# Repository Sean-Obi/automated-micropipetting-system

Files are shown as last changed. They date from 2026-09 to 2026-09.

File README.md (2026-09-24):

# Automated Micropipetting System - Gantry + Linear Actuator + Touchscreen

A low-cost, bench-top pipetting robot that lets users with tremors, fatigue or limited upper-limb mobility pipette independently. A modified Ender-3 gantry positions an actuator-driven 3D-printed micropipette over labware, and the whole run is set up from a Nextion touchscreen: pick a source, the destination wells and a volume, then press start.

Built as the Design & Prototyping group project built by nine second-year Molecular Bioengineering students at Imperial College London, supervised by Dr Ian Radcliffe.

> ❗️**Prototype, not a certified lab instrument.** Accuracy was validated on the bench only. Don't use it for regulated or clinical work.

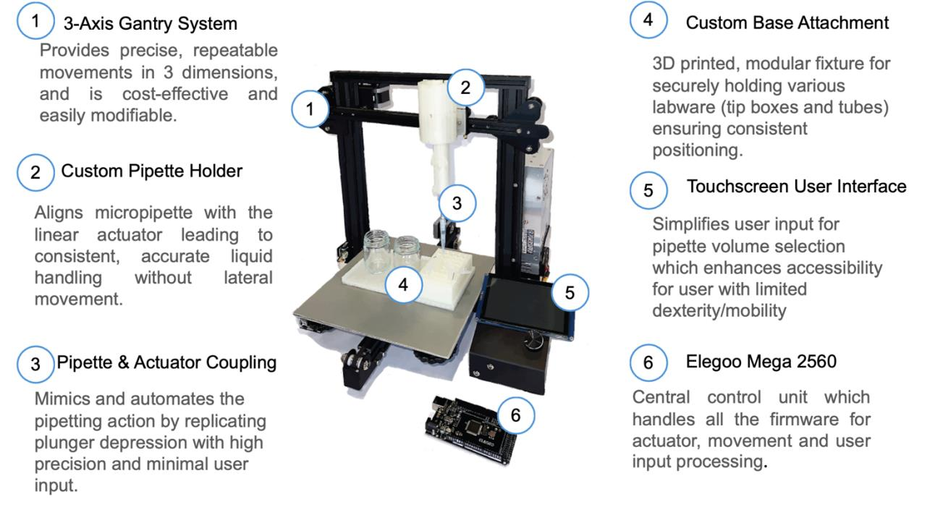
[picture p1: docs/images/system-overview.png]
System overview


---

## Features
- **3-axis Cartesian gantry** built on a Creality Ender-3 frame, with A4988 drivers and end-stop homing on every axis.
- **Coordinated XY motion** using Bresenham-style interpolation, so both axes arrive together. Z always retracts to a safe height before any travel.
- **Actuator-driven pipette.** A 12 V linear actuator presses the plunger of an open-source, ISO 8655-compliant 3D-printed micropipette.
- **Touchscreen workflow.** Source → wells → volume → start on a 4.3" Nextion HMI, with input validation done on the display.
- **Tactile keypad** (4×3) as an alternative input, plus a **buzzer** for audio feedback at the start and end of each job.
- **Modular PLA base** with a 5×8 tube rack and two beaker slots in fixed, grooved positions.
- **£483.53** material cost, against more than £35,000 for commercial liquid handlers.

---

## Hardware
- Elegoo Mega 2560 R3 (Arduino Mega compatible)
- Creality Ender-3 3D printer (frame, rails, NEMA17 steppers, end-stops, PSU)
- 3 × A4988 stepper driver modules
- Actuonix Linear Actuator Control (LAC) board + linear actuator
- 3D-printed adjustable micropipette (3 mL syringe) + custom pipette/actuator holder
- Nextion NX4827T043 4.3" HMI touchscreen + microSD card
- 4×3 membrane keypad, piezo buzzer
- 3 × LM2596 buck converters, custom interface PCB

Full part list with suppliers and prices: [`hardware/BOM.csv`](hardware/BOM.csv).

### Interface PCB
A 2-layer, 132 × 80 mm board that carries the three A4988 drivers, power inputs and all device connectors, with a 2×14 header to the Mega. KiCad files and Gerbers are in [`hardware/`](hardware/).

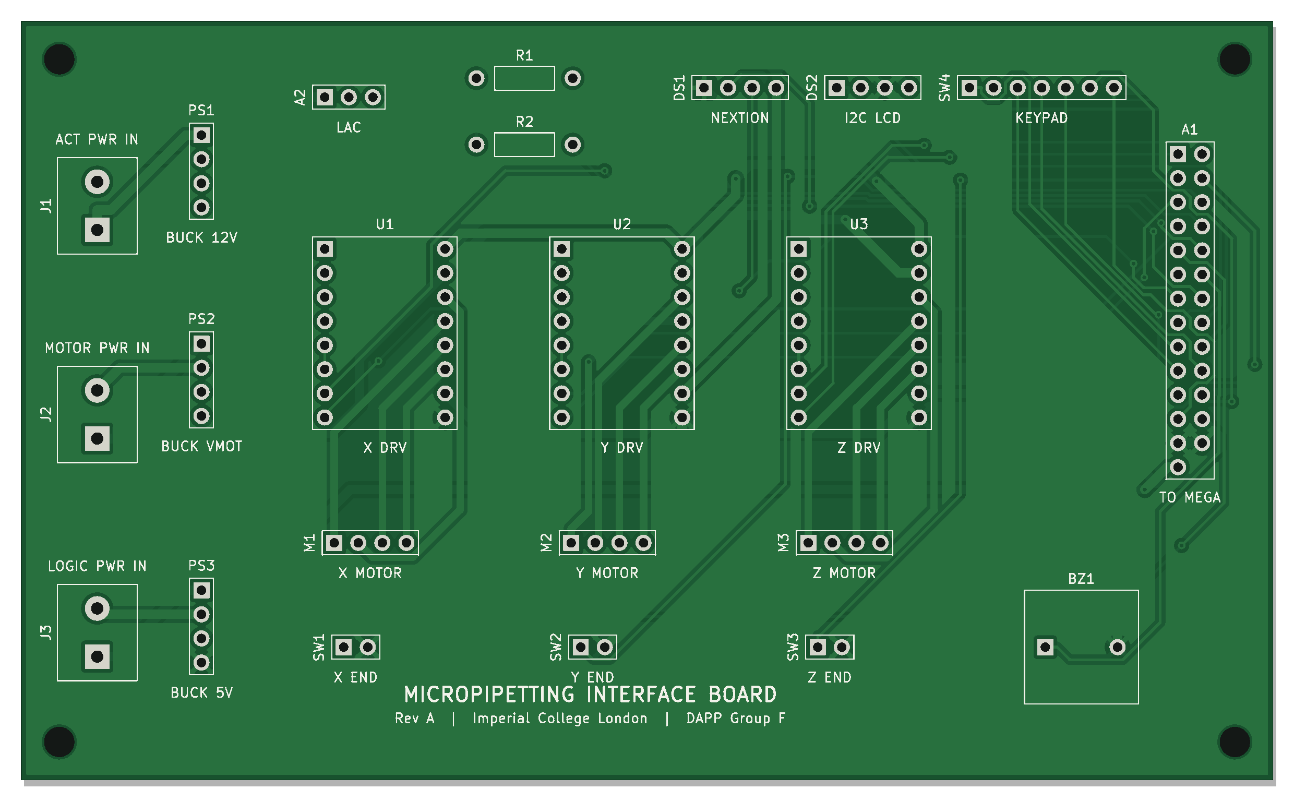
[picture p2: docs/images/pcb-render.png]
PCB render


> The layout in this repo is a 2026 reconstruction from the report schematic, not the original files sent to JLCPCB. See [`hardware/README.md`](hardware/README.md#board-layout).

### Power
- Mains supplies the Ender-3 PSU (24 W total draw).
- **12 V rail** (via buck converter) powers the LAC board and actuator.
- **5 V rail** (via buck converters) powers the Mega, the A4988 logic and the Nextion.
- A separate buck converter supplies the stepper motor voltage (VMOT).

> Set every LM2596 output with a multimeter **before** connecting anything. They ship at arbitrary voltages.

---

## Pinout / Wiring

| Component | Signal | Mega Pin |
|---|---|---|
| X axis | STEP / DIR / End-stop | **6** / **7** / **5** |
| Y axis | STEP / DIR / End-stop | **9** / **10** / **8** |
| Z axis | STEP / DIR / End-stop | **12** / **13** / **11** |
| LAC board | VC (position signal) | **4** (via R2, with R1 pull-up) |
| Nextion | RX / TX | **TX1 (18)** / **RX1 (19)** |
| Keypad | Rows / columns | **22, 24, 26, 28, 30, 32, 34** |
| Buzzer | + | **2** |
| A4988 | VDD / VMOT | 5V / motor buck output |
| A4988 | SLP ↔ RST | Tied together |
| End-stops | Switch → GND | `INPUT_PULLUP`, triggered = `HIGH` |

> Note: the report's schematic figure shows DIR/STEP swapped, the buzzer on D52 and the Nextion on TX0/RX0. The table above follows the firmware, which is what actually ran. Full schematic: [`hardware/pcb_design.kicad_sch`](hardware/pcb_design.kicad_sch).

---

## Software Requirements
Arduino IDE 1.8+ or Arduino IDE 2.x. **No external libraries** are needed. The sketch only uses the Arduino core (`Serial`, `Serial1`, `tone()`).

For the touchscreen:
- **Nextion Editor** to edit the `.HMI` and compile the `.tft`.

---

## Installation
1. **Clone the repository**
   ```bash
   git clone https://github.com/your-username/automated-micropipetting-system.git
   cd automated-micropipetting-system
   ```
2. Wire the system per the pin table above, and set the A4988 current limits and buck converter voltages.
3. Open `firmware/pipetting_controller/pipetting_controller.ino` in the Arduino IDE.
4. Select **Board → Arduino Mega or Mega 2560** and the correct port.
5. **Verify/Compile**, then **Upload**.
6. Copy the Nextion `.tft` to a FAT32 microSD card, insert it into the display and power it on to flash.
7. (Optional) Open **Tools → Serial Monitor** at **9600 baud** to watch the job logs.

---

## Configuration

Edit these constants near the top of the sketch. All positions are in **steps from home**:

```cpp
const long Z_SAFE_HEIGHT = 1700;   // travel height between positions
const long Z_WORK_HEIGHT = 300;    // tip-in-liquid height
unsigned long stepDelayXY = 1500;  // µs, XY step half-period (lower = faster)
unsigned long stepDelayZ  = 1200;  // µs, Z step half-period
const long MAX_HOMING_STEPS_Z = MAX_BACKWARD_Z + 100;  // Z homing timeout
```

Labware positions come from calibration and must be re-measured if the base changes:
```cpp
Coord wells[]   = { { 890, 500 }, { 940, 500 }, ... };  // 5×8 rack, 50-step pitch
Coord beakers[] = { { 400, 700 }, { 670, 700 } };       // left, right
```

Step resolution (from calibration):
- **X:** ~0.199 mm/step
- **Y:** ~0.205 mm/step
- **Z:** 0.04 mm/step

---

## How It Works

1. **Homing**  
   At power-up, each axis drives toward its end-stop (X → Y → Z) to set an absolute zero. Z then rises to `Z_SAFE_HEIGHT`.

2. **Job Entry**  
   The user steps through the Nextion screens (source type → beaker or input well → output wells → volume). The display checks the inputs, then sends a single packet over `Serial1`, terminated by `#`.

3. **Packet Parsing**  
   `parsePacket()` decodes the ASCII fields (`I=` input well, `O=` output wells) and the 4-byte little-endian fields (`V=` volume, `B=` beaker side, `T=` source type), then plays a confirmation beep.

4. **Execution**  
   The gantry travels to the source and then to each output well in turn. At every stop, `holdZatWorkHeight()` lowers the tip, dwells for 3 s, then retracts. Z always returns to safe height before any XY move.

5. **Return**  
   The head goes back to (0, 0), the end melody plays, and the buffer clears ready for the next job.

---

## Usage

1. Plug in the system and wait for homing to finish.
2. Fill the source beaker or tubes and place them in the marked slots. Fit a fresh tip.
3. On the touchscreen, choose **Beaker** or **Tubes**, then pick the source.
4. Tap the output wells and press **Confirm**.
5. Enter the volume in µL and tap **Start Pipetting**.
6. Two beeps confirm the job, and a melody plays when the head is back home.
7. Remove the tip by hand. There is no auto-eject yet.

Full walkthrough with screenshots: [`docs/user-guide.md`](docs/user-guide.md).

---

## Data Output

### Serial Monitor (9600)
```
Ready to receive Nextion packets...
Input Well: 0
Output Wells: 12,13,14,
Volume: 74
Beaker Side: 1
Source Type: 1
```

### Nextion Packet Format
```
T=<4B> B=<4B> I=<digits> O=<d>,<d>,...; V=<4B> #
```
| Field | Meaning |
|---|---|
| `T` | Source type: 1 = beaker, 2 = tubes |
| `B` | Beaker side: 1 = left, 2 = right |
| `I` | Input well index (0–39) |
| `O` | Output well indices, `;`-terminated |
| `V` | Volume in µL |

### Debug Commands (USB Serial)
| Command | Action |
|---|---|
| `X0` | Re-home X |
| `Y0` | Re-home Y |
| `Z0` | Re-home Z |

---

## Results

- **Volume accuracy:** the pipette alone was calibrated to within ±1% of target. The actuator adds extra uncertainty at system level, and accuracy drops at low volumes.
- **Cross-contamination:** no visible carryover in dye-then-clear runs with tip changes. This was checked by eye only.
- **Gantry:** the step-to-distance response is linear on all axes ([calibration](docs/calibration.md)).
- **User testing (n = 20):**
  - 90% rated lab fit 4–5/5.
  - 75% needed minimal or no instructions.
  - The top requests were a bigger screen, larger touch targets and tactile buttons.

Full evaluation: [`docs/testing.md`](docs/testing.md).

---

## Troubleshooting

- **An axis runs into the frame during homing**
  - Check the end-stop wiring and that it reads `HIGH` when pressed (`LIMIT_PRESSED = HIGH`).
  - XY homing has no step limit. Cut power or press reset if a switch fails.

- **The touchscreen does nothing when you press Start**
  - Nextion TX must go to Mega **RX1 (19)** and Nextion RX to **TX1 (18)**. The crossover matters.
  - Both sides need to be at **9600 baud**.
  - Check that the packet ends with `#`. Watch the Serial Monitor for the `Input Well:` lines.

- **The tip misses the wells**
  - Re-home with `X0` / `Y0` / `Z0`. Position isn't re-homed between jobs, so lost steps accumulate.
  - Re-measure `wells[]` / `beakers[]` if the base has moved.

- **A motor stutters, skips or runs hot**
  - Re-set the A4988 current limit on the trim pot.
  - Increase `stepDelayXY` / `stepDelayZ` to slow the motion.
  - Check that VMOT is present and the driver has airflow or a heatsink.

- **A motor runs backwards**
  - Swap one coil pair (1A/1B) on that driver.

- **The tip doesn't reach the liquid, or it crashes into the tube bottom**
  - Adjust `Z_WORK_HEIGHT`.

---

## Notes & Limitations
- **The volume isn't used by the firmware yet.** `V=` is parsed and logged, but this sketch doesn't generate the actuator PWM. Actuation happens outside this file.
- **16-bit `int` on AVR.** The 4-byte field decoding shifts by 16 and 24 bits, which overflows a 16-bit `int`. It works only because the upper bytes are zero. It should use `int32_t`.
- **Everything is blocking.** There's no cancel or emergency stop mid-job.
- **The keypad isn't implemented here.** It is wired, but this sketch doesn't read it.
- **Tips are ejected manually.** Servo-driven ejection and a tip bin are on the roadmap.
- **Materials.** PLA parts suit prototyping only. The pipette–carriage joint needs a stiffer mount.
- **The volume range is inconsistent across sources.** The spec says 100–1000 µL, the UI guide 10–100 µL, and testing covered 30–100 µL.

More detail: [`firmware/README.md`](firmware/README.md#known-issues).

---

## Project Structure

```
automated-micropipetting-system/
├── firmware/
│   ├── pipetting_controller/
│   │   └── pipetting_controller.ino   # Gantry, homing, Nextion packet parser
│   └── README.md                      # Pinout, protocol, known issues
├── hardware/
│   ├── pcb_design.kicad_pro           # KiCad project
│   ├── pcb_design.kicad_sch           # Schematic
│   ├── pcb_design.kicad_pcb           # Board layout (reconstructed)
│   ├── pcb_design_gerbers.zip         # Gerbers + drill files
│   ├── apms.pretty/                   # Project footprint library
│   ├── pcb_design.pdf                 # Plotted schematic
│   ├── schematic.png                  # Original figure from the report
│   ├── BOM.csv                        # Bill of materials (£483.53)
│   ├── tools/                         # Schematic + board generation scripts
│   └── README.md                      # Power rails, drivers, wiring
├── hmi/
│   └── README.md                      # Nextion screen flow
├── cad/
│   └── README.md                      # SolidWorks parts (base, holders)
├── docs/
│   ├── images/                        # Figures
│   ├── calibration.md                 # Gantry step calibration
│   ├── testing.md                     # Accuracy, contamination, user testing
│   ├── user-guide.md                  # Operating instructions
│   └── final-report.pdf               # Full project report
└── README.md
```

---

## Team
Ben Jones · Jenna du Preez · Kailin Wang · Leonardo Grimaldi · **Sean Obi** · Sheena Ling · Sumaiyah Zaman · Tayeb Tadlaoui · Yasmine Marenzi

### My Contributions (Sean Obi)
- **PCB design.** Designed the custom interface PCB (schematic and layout), manufactured by JLCPCB.
- **Electronics lead.** System wiring and power distribution (12 V actuator rail, 5 V logic), and integration of the drivers, LAC board, keypad, display and buzzer.
- **Firmware.** Co-developed the Arduino controller: homing, XY motion and Nextion packet handling.
- **Gantry.** Assembled the Ender-3 conversion.
- **User testing.** Coordinated the n = 20 study.
- **Final report.** Co-authored it.

---

## Acknowledgements
- Dr Ian Radcliffe (supervisor)
- Imperial Disability Advisory Services and Dr Katherine Dean
- Ms Iris Latham (disability consultant) and Dr Tweety Tang (user-testing sessions)
- Brennan, Bokhari & Eddington: *Open Design 3D-Printable Adjustable Micropipette that Meets the ISO Standard for Accuracy* (Micromachines, 2018)
- Creality Ender-3 · Pololu A4988 · Actuonix LAC · Nextion Editor

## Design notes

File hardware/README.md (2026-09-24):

# Hardware

| File | Contents |
|---|---|
| `pcb_design.kicad_pro` | KiCad project (KiCad 7 format; opens in 7, 8 and 9) |
| `pcb_design.kicad_sch` | Schematic |
| `pcb_design.kicad_pcb` | Board layout (reconstructed; see below) |
| `pcb_design_gerbers.zip` | Gerbers and drill files exported from the reconstructed layout |
| `apms.pretty/`, `fp-lib-table` | Project footprint library |
| `pcb_design.pdf` | Plotted schematic |
| `schematic.png` | Original schematic figure from the report (Appendix F) |
| `tools/` | Scripts that generate the schematic and board |
| `BOM.csv` | Bill of materials |

---

## Board Layout

PCB render

> **Reconstruction.** The original 2025 layout files and the Gerbers sent to JLCPCB aren't in this repo. This layout was rebuilt in 2026 from the report's schematic figure and auto-routed with Freerouting. It is electrically equivalent to the schematic, but it is not the board that was manufactured.

**Board**
- 132 × 80 mm, 2 layers, 1.6 mm thick, with four M3 mounting holes.
- GND pour on both layers.

**Track widths**
| Net class | Nets | Width |
|---|---|---|
| Power | GND, +5V, VMOT, actuator and logic supply | 1.0 mm |
| Motor | Stepper coils | 0.8 mm |
| Signal | Everything else | 0.3 mm |

The board passes KiCad DRC with **0 violations and 0 unconnected pads**.

**On-board**
- 3 × Pololu-format A4988 sockets (X/Y/Z)
- R1/R2 on the LAC control line
- Buzzer
- 3 × 5.08 mm screw terminals for the power inputs

**Connected by header**
- Motors (4-pin) and end-stops (2-pin)
- The three LM2596 modules (IN+, IN−, OUT+, OUT−)
- LAC board, Nextion, legacy I²C LCD (not fitted) and keypad
- A 2×14 **TO MEGA** header carrying every Mega signal

---

## Schematic

The `.kicad_sch` is redrawn from the report figure, with two changes:

1. **It shows all three axes.** The original figure shows one representative driver, motor and end-stop.
2. **Its pin assignments follow the firmware, which is what actually ran.** Where the report figure differs, the firmware wins:

| Signal | Report figure | Schematic / firmware |
|---|---|---|
| X DIR / STEP | D6 / D7 | D7 / D6 |
| Buzzer | D52 | D2 |
| Nextion | TX0 / RX0 | Serial1: TX1 (D18), RX1 (D19) |

Connectivity uses net labels, so every connection is explicit. Every symbol has a footprint from the project library, and **Tools → Update PCB from Schematic** matches the layout.

Before building from these files, check these points against the physical build:

- The values of R1 and R2 on the LAC control line are not given in the report.
- The keypad pin order onto D22–D34 is as drawn in the report.
- `VMOT_GND` and `LAC_V-` are left as separate returns, as drawn. Tie them to GND if the supplies share a ground.

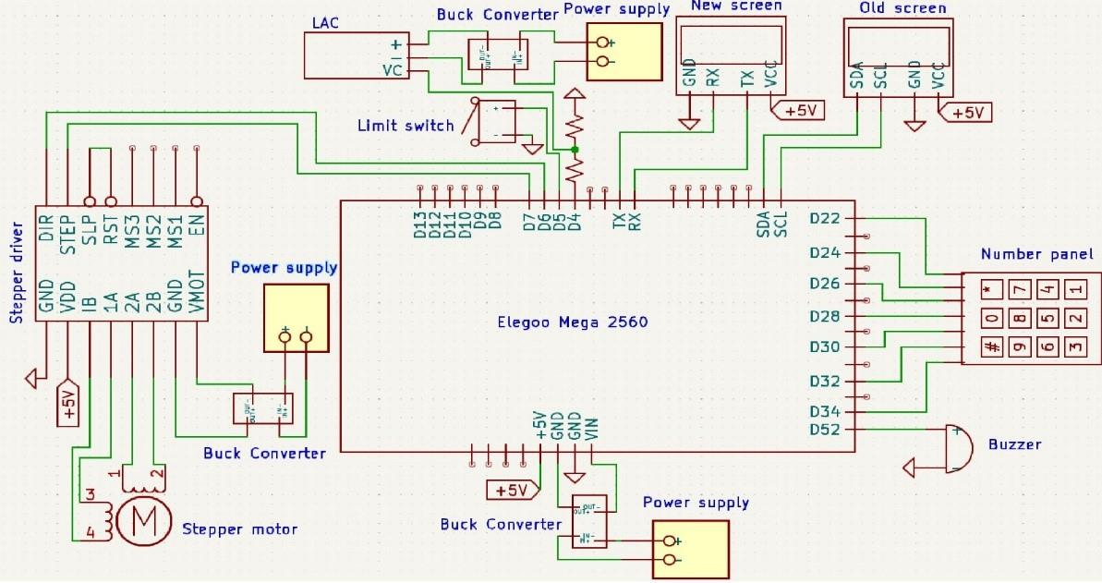
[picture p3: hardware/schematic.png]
Original schematic


---

## Power

| Rail | Source | Loads |
|---|---|---|
| Mains → 24 V | Ender-3 built-in PSU | Input to buck converters |
| 12 V | Buck converter (LM2596) | Linear actuator via LAC board |
| 5 V | Buck converters (LM2596) | Mega 2560, A4988 logic, Nextion display |
| Motor supply | Buck converter → A4988 VMOT | Stepper coils |

The system draws about 24 W in total.

**Before connecting anything**, set each LM2596 output with a multimeter. The modules ship at arbitrary voltages and will kill the Mega or the display if left unset.

---

## Stepper drivers

There are three A4988 carriers, one each for X, Y and Z (the BOM includes one spare). STEP and DIR go to the Mega (see [firmware pinout](../firmware/README.md#pinout)). Tie SLP and RST together high.

Set the current limit on each driver using the trim pot:

> V_ref = I_max × 8 × R_sense

Set it for the Ender-3's stepper motors (Creality 42-series), and check R_sense on your particular carrier.

---

## Actuator

The linear actuator is driven through an Actuonix Linear Actuator Control (LAC) board. The Mega sends a PWM/RC position signal to the LAC. The LAC closes the position loop and drives the actuator from the 12 V rail. The actuator's rod is mechanically coupled to the pipette plunger, as shown in the [pipette mechanism image](../docs/images/pipette-mechanism.png).

---

## I/O

- **Nextion display:** UART on Serial1 (TX1/RX1), powered from 5 V.
- **Keypad:** 4×3 matrix on D22–D34.
- **Buzzer:** D2.
- **End-stops:** the stock Ender-3 mechanical switches, one per axis.
- **Old I²C LCD:** still shown on the schematic but no longer used.

---

## Bill of materials

See [`BOM.csv`](BOM.csv). The total comes to **£483.53**. The two largest items are the Ender-3 (£139) and the custom PCB (£99.22).

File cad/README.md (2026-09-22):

# CAD

The custom parts were designed in SolidWorks and printed in PLA using FDM. Add the `.SLDPRT` / `.SLDASM` sources and exported `.STL` files here:

| Part | Function |
|---|---|
| Base attachment | Bolts to the Ender-3 bed and holds labware in fixed, grooved slots |
| Microcentrifuge tube holder | 5×8 rack for 1.5 mL tubes, matching the `wells[]` grid in firmware |
| Pipette holder | Clamps the pipette to the X-carriage using the existing mounting holes |
| Actuator holder | Screws onto the pipette holder and keeps the actuator coaxial with the plunger |

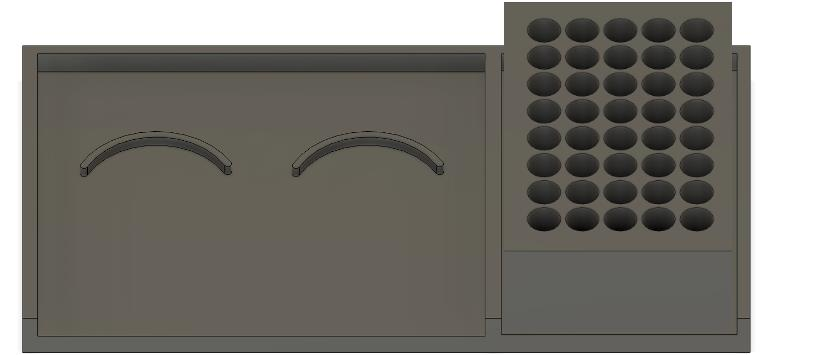
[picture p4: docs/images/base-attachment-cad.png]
Base attachment and tube holder


The micropipette itself is the open-source design by Brennan, Bokhari & Eddington (Micromachines, 2018). Link to their files rather than re-hosting them, and check their licence terms.

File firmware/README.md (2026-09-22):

# Firmware

`pipetting_controller/pipetting_controller.ino` is a single Arduino sketch for the Elegoo Mega 2560. It homes the gantry, receives jobs from the Nextion display on `Serial1`, and moves the pipette head between labware positions.

---

## Build

- **Arduino IDE:** open the sketch folder, select board **Arduino Mega or Mega 2560**, and upload. No external libraries are needed.
- **arduino-cli:**
  ```bash
  arduino-cli compile --fqbn arduino:avr:mega firmware/pipetting_controller
  arduino-cli upload  --fqbn arduino:avr:mega -p <PORT> firmware/pipetting_controller
  ```

---

## Pinout

| Signal | Mega pin | | Signal | Mega pin |
|---|---|---|---|---|
| X end-stop | D5 | | Z end-stop | D11 |
| X STEP / DIR | D6 / D7 | | Z STEP / DIR | D12 / D13 |
| Y end-stop | D8 | | Buzzer | D2 |
| Y STEP / DIR | D9 / D10 | | Nextion RX / TX | TX1 / RX1 (Serial1) |
| Keypad rows/cols | D22–D34 (per schematic) | | USB debug | Serial @ 9600 |

The end-stops use `INPUT_PULLUP`, and a limit reads as triggered when it is `HIGH`.

---

## Configuration

All positions are in **steps from home**, not mm (≈0.2 mm/step in X and Y, 0.04 mm/step in Z; see [calibration](../docs/calibration.md)).

| Constant | Value | Meaning |
|---|---|---|
| `Z_SAFE_HEIGHT` | 1700 | Travel height for all XY moves |
| `Z_WORK_HEIGHT` | 300 | Tip-in-liquid height |
| `MAX_HOMING_STEPS_Z` | 1800 | Z homing timeout |
| `stepDelayXY` / `stepDelayZ` | 1500 / 1200 µs | Step half-periods; sets speed |
| `wells[40]` | 5 × 8 grid, 50-step pitch | Tube rack origin at (890, 500) |
| `beakers[2]` | (400, 700), (670, 700) | Left / right source beaker |

If you change the base attachment, re-measure the `wells[]` and `beakers[]` coordinates.

---

## Motion

- **Homing:** runs X → Y → Z at boot. Z then retracts to safe height.
- **XY moves:** interpolated with an integer Bresenham-style error accumulator, so both axes arrive together. Z always rises to safe height before any XY move.
- **Z moves:** check the Z end-stop on the way down and re-zero if it trips early.
- **Pipetting step:** at each labware position, `holdZatWorkHeight()` lowers the head, dwells for 3 s, then retracts.
- **Debug commands:** sending `X0`, `Y0` or `Z0` over USB serial re-homes that axis.

---

## Nextion → Mega protocol

A job is one packet terminated by `#`. The fields can appear in any order.

| Field | Encoding | Meaning |
|---|---|---|
| `I=<digits>` | ASCII | Input (source) well index, 0–39 |
| `O=<d>,<d>,…;` | ASCII, `;`-terminated | Output well indices (≤ 40) |
| `V=` + 4 bytes | uint32 little-endian (Nextion `prints va,4`) | Volume, µL |
| `B=` + 4 bytes | uint32 LE | Beaker side: 1 = left, 2 = right |
| `T=` + 4 bytes | uint32 LE | Source type: 1 = beaker, 2 = tubes |

The job then runs in this order: confirmation beep → source → each output well in turn → return to (0, 0) → end melody.

---

## Known issues

These are in the sketch as submitted and are left unfixed so the code matches the report.

1. **The volume is parsed but not used.** `V=` is decoded and logged, but this sketch never generates the actuator PWM. Plunger actuation and the volume-to-position mapping via the LAC board sit outside this file. If that code exists in another revision, it belongs here.
2. **16-bit `int` overflow on AVR.** `data[i+4]<<16` and `data[i+5]<<24` shift a promoted 16-bit `int`, which is undefined behaviour. It works in practice only because the upper bytes are zero for small values. Fix it by declaring `volume` etc. as `int32_t`/`long` and casting each byte to `uint32_t` before shifting.
3. **XY homing is unbounded.** `homeAxisX/Y` loop until the switch trips. `MAX_BACKWARD_XY` is declared but never used, so a failed end-stop drives the axis indefinitely. Only Z has a homing timeout.
4. **Position drift.** After each job, the X and Y positions are reset to 0 without re-homing, so any lost steps accumulate across jobs.
5. **Everything blocks.** There is no way to cancel or emergency-stop mid-job, and the UART buffer is not serviced while motors run.
6. **The keypad is not implemented here.** It is wired to D22–D34 per the schematic, but this sketch never reads it.

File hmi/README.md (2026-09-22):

# Nextion HMI

The interface was built in the Nextion Editor for an NX4827T043 (4.3", 480×272, resistive touch). Place the project files here:

- `pipetting_ui.HMI`: the editable Nextion Editor source
- `pipetting_ui.tft`: the compiled file, loaded onto the display from a FAT32 microSD card

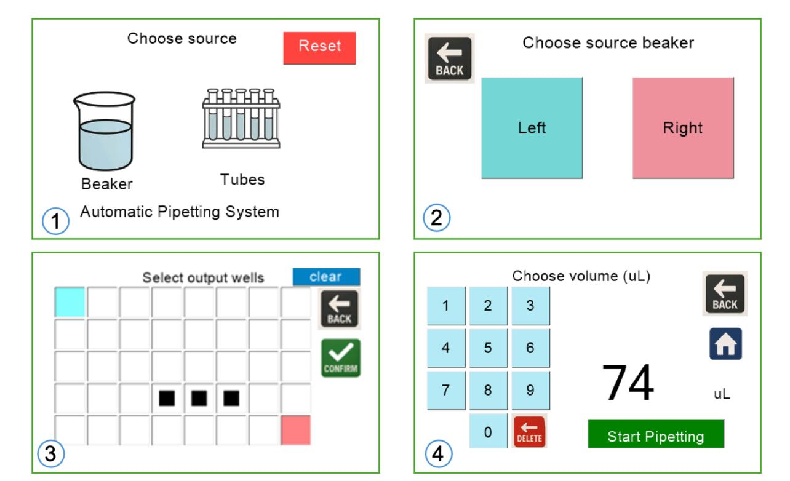
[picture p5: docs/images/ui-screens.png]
UI screens


---

## Screen flow

| Page | Purpose | Sends |
|---|---|---|
| 0 – Choose source | Beaker or Tubes, plus Reset | `T=` |
| 1a – Source beaker | Left / Right (beaker path only) | `B=` |
| 1b – Input well | 5×8 grid, single select + Confirm (tubes path only) | `I=` |
| 2 – Output wells | 5×8 grid, multi-select, Clear / Confirm | `O=…;` |
| 3 – Volume | Numeric keypad, Delete, Start Pipetting | `V=` then `#` |

---

## Validation (done on the display)

- Exactly one input well is required, with a warning if none is selected.
- At least one output well is required.
- A well cannot be both input and output, and this is enforced even when navigating back.
- The volume must be within range, otherwise a warning appears briefly.

The UI colours follow the accessibility guidance from the Access All Areas in Labs project.

> **Note:** the user guide gives the on-screen volume range as 10–100 µL, and bench testing covered 30–100 µL, while the design specification targets 100–1000 µL. Check which limit is set in the `.HMI` before publishing.

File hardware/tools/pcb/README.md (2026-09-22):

# PCB generation scripts

These scripts rebuild `pcb_design.kicad_pcb` from the schematic. They need KiCad 7 (`pcbnew` Python module + `kicad-cli`) and Java 21 for [Freerouting](https://github.com/freerouting/freerouting).

Run the commands below from `hardware/`, in order:

```bash
python3 tools/make_sch.py pcb_design.kicad_sch                  # schematic
python3 tools/pcb/footprints.py apms.pretty                      # footprint library
kicad-cli sch export netlist -o board.net pcb_design.kicad_sch  # netlist
python3 tools/pcb/build_board.py board.net apms.pretty placed.kicad_pcb board.dsn   # placement
python3 tools/pcb/prep_dsn.py board.dsn routed_in.dsn          # net classes: power 1.0 mm, motor 0.8 mm, signal 0.3 mm
java -jar freerouting.jar -de routed_in.dsn -do board.ses -mp 40 --gui.enabled=false   # autoroute
python3 tools/pcb/finish_board.py placed.kicad_pcb board.ses pcb_design.kicad_pcb     # import routes, clean up, GND pours
```

Freerouting is non-deterministic, and a run can occasionally drop a net. `finish_board.py` prints the number of unrouted connections. Re-run the routing step until it reports 0.

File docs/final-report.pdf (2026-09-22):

## Automated Micro pipetting System for Users with Limited Dexterity

Final Report

Team Members
Ben Jones
Jenna du Preez
Kailin Wang
Leonardo Grimaldi
Sean Obi
Sheena Ling
Sumaiyah Zaman
Tayeb Tadlaoui
Yasmine Marenzi

Supervisor: Dr Ian Radcliffe

Revision | Date | Author | Description
A | 18/06/2025 | Group F | Final release

18 June 2025
Word Count: 4986

## Abstract

Manual Micro pipetting is essential in wet lab environments but presents significant challenges for individuals with tremors, fine motor impairments or limited dexterity. This accessibility barrier limits participation and independence in scientific research and lab work. This project addresses this gap by developing a compact, automated pipetting system to enable independent use by individuals suffering from physical disabilities. This system enables accurate, repeatable pipetting without the need for sustained fine motor control, whilst achieving volume delivery within ±1% of target volume.
The system integrates a 3-axis Gantry system, linear actuator and touchscreen/keypad interface to eliminate the requirement of precise manual dexterity. By mechanising the liquid aspiration and dispensing processes, this design helps to reduce human error and physical strain, while maintaining required precision for laboratory protocols. The core objectives were to increase independence of disabled users, reduce reliance on assistance in laboratory environments, and maintain the accuracy of traditional pipetting.
Development priorities include ergonomics, mechanical stability, a comprehensive user interface, and consistent volume control. A compact design and lightweight construction ensure the device is portable, even for users with reduced strength or reach. The device accommodates standard pipette tips and volumes and is operable via simple interface elements such as a numerical keypad or touchscreen inputs. Initial research involving Imperial College Disability Services, informed the design and validated the systems usability and ability to improve accessibility.
In conclusion, the Automated Micro pipetting System demonstrates a viable approach to enhancing accessibility within laboratory environments. It offers a scalable solution for increasing inclusion and accessibility in research and education without compromising scientific performance.
Future developments may incorporate programmable volume sequences and mobile app integration to help further streamline workflows and enhance ease of use.

## Acknowledgements

Our sincerest thanks go to Ian Radcliffe, our project supervisor, whose expert oversight and thoughtful guidance was invaluable throughout the development process. His input on design feasibility and manufacturing process played a key role in refining our final design.

We are also grateful to the Imperial Disability Advisory Services and Dr Katherine Dean for their contributions during the initial research phase. Their input helped shape our project’s direction by highlighting key accessibility considerations and guiding our early design decisions.

We appreciate the assistance of Ms Iris Latham - our disability consultant. Her insight on the unique experiences of people with limited motor skills allowed us to make the necessary improvements for a more accessible and inclusive design.

A special thanks goes to Ms Mandy Mak, Mr Paschal Egan, and Mr Tariq Malik for their constructive feedback during the design phase. Their insights prompted significant improvements, making our final design more practical and effective.

Lastly, we’d like to thank Dr Tweety Tang for organising and facilitating user feedback sessions to ensure our project aligned with our group mission to improve accessibility.

## Contents

## 1 Introduction

Manual micro pipetting is a core technique in biological and chemical laboratories. It is essential for obtaining accurate experimental results. However, individuals with fine motor impairments, such as tremors, reduced dexterity, or limited upper limb mobility, often face significant challenges in performing these tasks. For some, pipetting may be time-consuming, frustrating, or entirely inaccessible without assistance. This creates a physical and professional barrier, limiting both independence in laboratory work and equal participation in scientific research and education.

To address this critical accessibility gap, this project focused on the design and development of a low-cost, compact, automated micropipetting system. The goal was to create a device that enables users with physical impairments to independently and accurately perform pipetting tasks, thereby promoting inclusivity in laboratory environments.

Rather than targeting a single type of disability, the project was designed with a broad spectrum of upper body impairments in mind. This inclusive approach maximizes the potential impact of the device. The system is intended to assist individuals with tremors, who may struggle to hold even a beaker steadily; those with fatigue, who may find repetitive pipetting tasks exhausting; and users with limited mobility in one arm, who may be unable to operate a manual pipette but can interact with a touchscreen or interface, etc.

### 1.1 Background Research

Prior to selecting a pipetting system as the focus, the team conducted research into the broader challenges faced by individuals with disabilities in laboratory settings. This included reviewing academic literature, exploring public data on disability prevalence, and conducting interviews with individuals in STEM societies, educators, and disabled individuals with laboratory experience.

Figure 1: Prevalence of Disability Types
in the UK (%)
Figure | 2: | Key | Accessibility | Challenges
Reported by Disabled Users

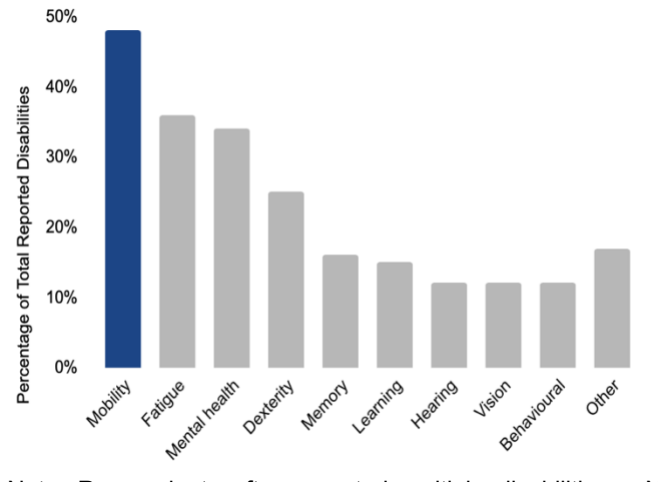
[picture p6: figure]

Note: Respondents often reported multiple disabilities; totals exceed 100% [1]

Note: Respondents were contacted through Royal Society of Chemistry, Imperial College disability services, etc

Upper body impairments and tasks requiring fine precision emerged as common themes. According to the UK House of Commons, Figure 1, mobility-related issues, including upper body mobility, are the most prevalent form of disability, with nearly 50% of disabled individuals reporting such challenges. Fatigue and dexterity were also highly reported, which our product directly targets. In our independent outreach, figure 2, participants frequently cited difficulties with fine motor tasks, reinforcing the need for solutions that support precision work.

The team also evaluated existing adaptive technologies in laboratory environments. While tools such as tactile microscopes, talking scales, and adjustable lab benches exist [2] [3] [4]; few solutions specifically support fine motor tasks for users with upper limb impairments. Commercial liquid-handling robots, like those from Tecan [5] and SPT Labtech [6], do offer automation but are typically expensive, complex, and designed for high-throughput industrial or research applications. They are unsuitable for day-to-day use by individuals requiring personal assistance in smaller academic or teaching laboratories. Moreover, they are rarely designed with accessibility for disabled users in mind.

This project seeks to bridge the gap between accessibility and precision by offering a compact, cost-effective, and user-friendly automated pipetting solution. Designed to integrate into standard lab protocols and compatible with common pipette tips and volumes, the system uses intuitive controls that require minimal manual dexterity. The resulting device supports independent operation by users with physical impairments, without compromising the accuracy essential to scientific research.

## 2 Requirements Definition

The Automated Micro Pipetting System was designed specifically with end users in mind, aiming to support individuals with upper body impairments in performing pipetting tasks independently and accurately. The key user requirements reflect the need for improved accessibility, usability, and precision, whilst ensuring seamless integration into standard laboratory environments and remaining intuitive and easy to use for those with limited dexterity.

Figure 3: Primary User Requirements

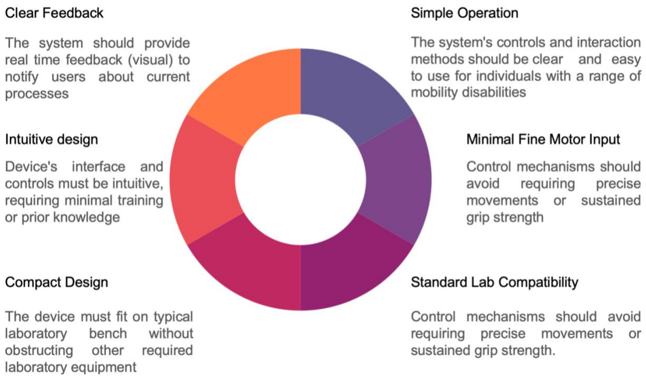
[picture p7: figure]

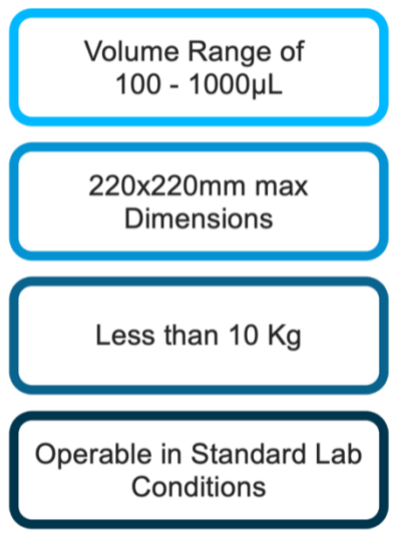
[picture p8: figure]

The requirements outlined in Figure 3 & 4 guided the electronic and mechanical design decisions, as well as the testing and evaluation strategies. They also serve as a benchmark to ensure the system’s success for meeting user needs and ensuring that accessibility enhancements don’t come at the expense of laboratory efficiency or accuracy.

## 3 Final Design

### 3.1 Assembly and Overview

The final design, which is outlined in Figure 5, is a compact, automated micro pipetting device specifically engineered to assist users with limited hand dexterity in performing accurate and independent liquid handling tasks. The system integrates precise and direct movements in 3 dimensions using stepper motors mounted on a modified 3D printer gantry system as a base (adapted from Ender 3 3D printer) [10]. This foundation provided a lower cost, robust mechanical platform and reduced the need for custom design and manufacturing. The pipette mechanism is operable through a user-friendly LCD touchscreen interface, allowing programmable volume control, live feedback, and intuitive operation. At the core of the pipetting mechanism is a custom designed 3-D printed pipette holder, designed to securely mount and operate an open-source 3D printed Adjustable Micropipette which complies with the ISO standards for accuracy [7]. This pipette can be operated mechanically by the system via an actuator to aspirate and dispense fluids with programmable volume control, set via the user-friendly interface. The user selects desired volume, and the microcontroller executes the movement sequence accordingly.
The design also includes a modular base component equipped to hold commonly used laboratory equipment such as pipette tip boxes, microcentrifuge tube racks and sharps containers. This module improves accessibility and enhances workflow within standard laboratory environments. The entire system has been designed to be compatible with standard micropipette tips and corresponding volume ranges, ensuring it integrates smoothly within existing laboratory setups.

Figure 4: Key Quantitative Requirements

Pipetting Volume Range: 100μL – 1000 μL, with ±1% volume accuracy (adhering to ISO standards [8]).
System Footprint: 220mm x 220mm maximum dimensions, to ensure laboratory bench compatibility [7]
Lightweight Design: Less than 10 kg to ensure it can be comfortably lifted and relocated to accommodate disabled users
Operable | within | Laboratory | Settings:
Should be operable in standard laboratory conditions (e.g. temperature in range 18-22°C [9])

Sources: [7] [8] [9]

Figure 5: Final Design Features of Automated micro–Pipetting System

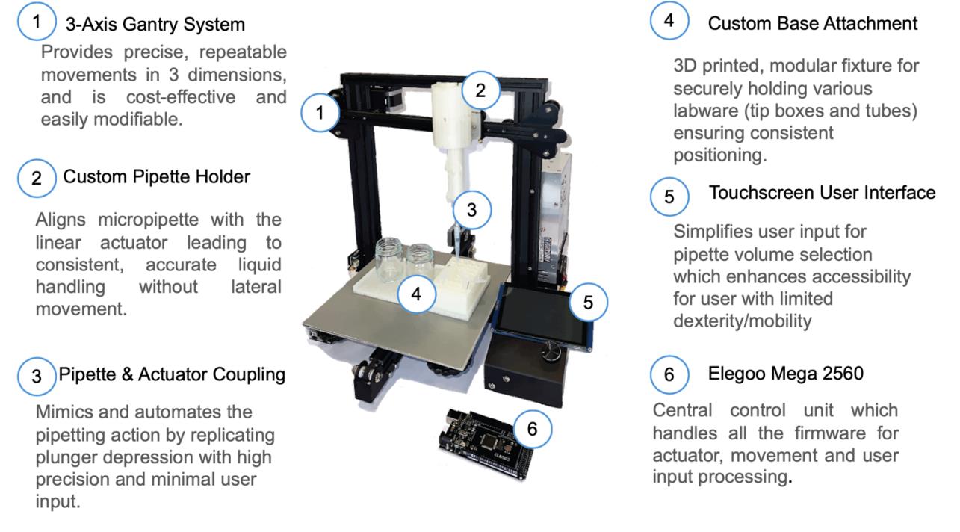
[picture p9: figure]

Note: Final design also includes electronic components not visible in diagram, such as LAC board, motors, motor drivers, buck converters and the linear Actuator

### 3.2 Gantry System

The gantry system forms the structural backbone of the device, enabling precise, repeatable movements in X, Y and Z planes. It is built upon the assembly of a Creality Ender 3D printer [10], selected for its affordability, structural rigidity and pre-integrated movement components. This includes linear rails, mechanical end-stop switches and lead screws allowing for smooth, accurate translational movements. The gantry system was calibrated by determining the number of stepper motor pulses required to translate a specific linear distance, allowing accurate mapping between step count and physical displacement along the axes. Empirical calculation showed us that there was a movement of 0.2mm per step in the Y and X direction, and a movement of 0.04mm per step in the Z direction. (Appendix I) To adapt this system, we replaced the stock stepper motor drivers with A4988 stepper motor drivers (figure 6), interfaced via a complementary circuit connected to a microcontroller (Elegoo Mega 2560). This modification ensures full integration with the custom electronics (Appendix F) and firmware, enabling precise pipette positioning through programmable control inputs. The travel limits are approximately 220mm in X and 220mm in Y, and 170mm in the Z dimension. Mechanical end-stops were retained along all the axes to enable consistent mapping of positions from startup, ensuring positional accuracy.
The configuration is as follows:
- X-axis: lateral movement of the pipette, allowing precise positioning across.
- Y-axis: forwards and backwards translation of base platform.
- Z-axis: Vertical movement to raise/lower the pipette for aspiration.

By moving the base platform into position, the system enables reproducible and automated positioning specific to liquid handling tasks being performed.

Figure 6: Elements of the Gantry System

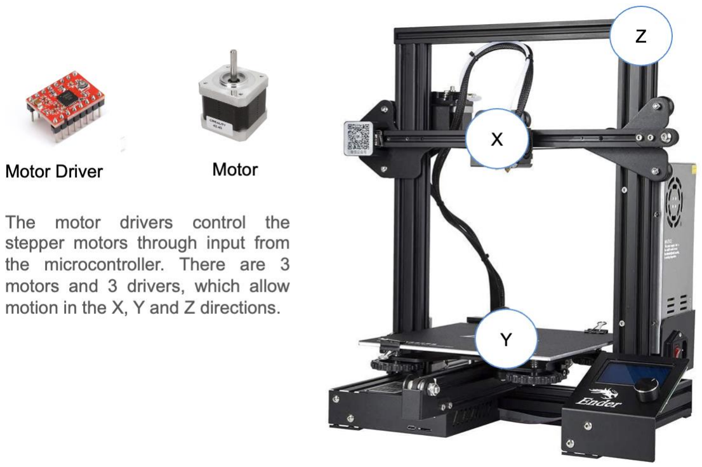
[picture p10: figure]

Source: [10] [11] [12]

### 3.3 Base Attachment

The base attachment was designed in SolidWorks (Figure 7) to slot onto and interface seamlessly with the gantry system. It acts as the main stage for labware and sample containers, housing secure slots for pipette tip boxes, microcentrifuge tubes, and other modular lab equipment. The positions of these slots are predefined on the plate, allowing for consistent accurate positioning throughout the automated pipetting process.

Figure 7: Base and Cuvette Holder CAD

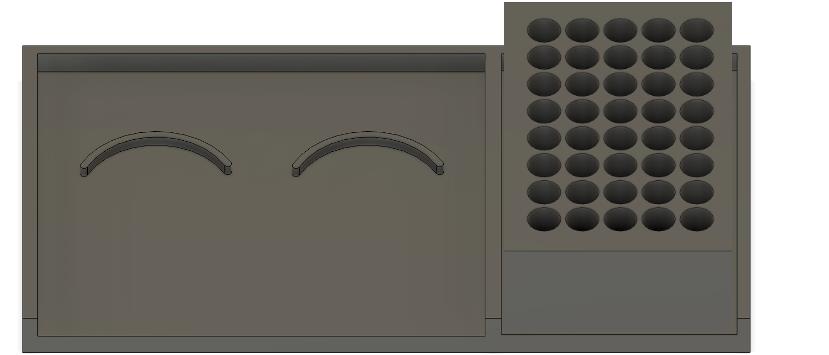
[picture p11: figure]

Note: Renderings of our custom designed microcentrifuge tube holder (left) and modular base attachment (right), both developed to ensure stable positioning of labware during automated pipetting processes

The base is securely affixed onto the printer bed, allowing for controlled movement in 3 dimensions via the Gantry System. This allows for precise translation of the labware elements directly under the pipette for tasks such as fluid dispensing or tip pickup.
This attachment is 3D printed from PLA, chosen for its rigidity, ease of printing, and mild chemical resistance [13] [14] [15]. Labware slots are custom designed to accommodate standard containers, for example the microcentrifuge tube holder and standard beaker sizes [16], ensuring easy slotting and stable positioning during dynamic motion. The integrated locating grooves also serve as guard rails, providing additional physical guidance to allow secure placement of labware even during dynamic motion, and assisting users with reduced hand dexterity by simplifying the loading process.

3.4 3D-Printed Adjustable Micropipette

The liquid handling system incorporates an open-source, 3D printable adjustable micropipette designed to meet ISO 8655 standards, representing accuracy, precision and reliability [17]. This pipette operates by actuating a disposable tip design syringe to a user specified point, enabling precise volume control without the necessity of complicated internal mechanisms. Figure 8 shows the sequence of events involved in pipette usage, demonstrating how the plunger displacement leads to liquid aspiration and dispensing.

Figure 8: Sequence of events involved in pipette usage

Note: Shows CAD modelling of operating modes. A - Latched position ready to aspirate, after the button is pressed releasing pipette to position B. B - Set position, screw position determines the displacement of plunger and therefore aspiration volume. C – The blowout position, plunger is pressed in dispensing liquid. D – Return to the latched position, ready to repeat process. [17]
The micropipette is composed of 3D-printed components fabricated using FDM with PLA filament, combined with readily available hardware such as disposable syringes and springs. The design utilises the evenly spaced graduations on the syringe barrel to set the desired volume, allowing for straightforward adjustment and calibrations.
The pipette is configured to 100-1000 μL, utilising a 3ml syringe, volume range allowing us to adhere to our project specifications.
Initial testing from the design process revealed that the syringe’s original graduation marks resulted in systematic error due to air compressibility effects [17]. To address this as part of the design we used, adjusted scale graduations were developed and affixed to the syringe, compensating for the accumulated error. With these adjustments, the pipette achieved compliance with ISO 8655, demonstrating accuracy and precision comparable to commercial micropipettes.

### 3.5 Actuator and Pipetting Mounting

Figure 8: Pipette Mechanism

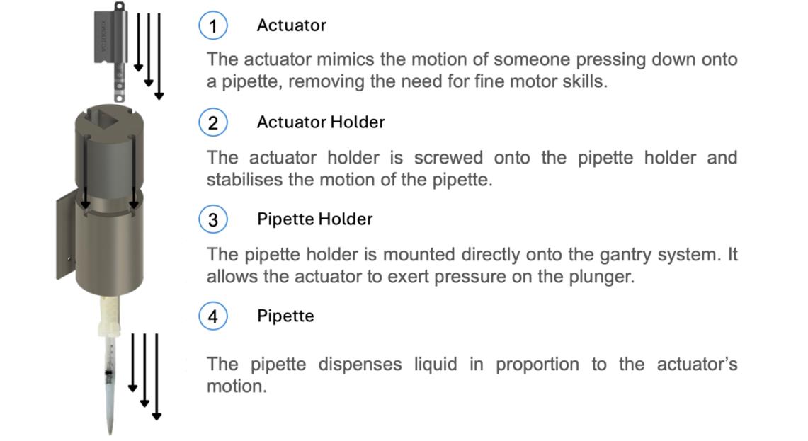
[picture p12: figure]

Note: Holders are 3D renderings of our CAD models, while pipette is an image of our actual product

The actuator is directly mounted onto the X-axis of the gantry system using a custom designed 3D printed attachment, which securely holds both the actuator and the micropipette in precise alignment with one another (Figure 8). This setup ensures that the actuator’s action is consistently transmitted to the pipette’s plunger, ensuring repeatable and controlled aspiration/dispensing. The actuator's extending arm is mechanically joined to the plunger, essentially replicating the manual action performed while pipetting.
The holder is designed to accommodate our specific 3D printed pipette, providing a secure fit with easy removal and insertion. Features were specially designed for alignment of the pipette and specific clamping mechanisms were introduced to minimise lateral movement and ensure repeatability, critical for maintaining volumetric precision. The bracket is printed from PLA, which offers sufficient rigidity for repeated use while being easy to manufacture using FDM 3D printing. It is directly attached to the gantry’s X-axis carriage using existing mounting holes, avoiding modifications to the pre-existing 3D printing frame helping maintain mechanical stability during operations provided by the 3D printer kit.
To control the actuator, a Linear Actuator Control (LAC) board is used, allowing for communication between the microcontroller and actuator. The actuator operates at 12 V, which is supplied by an external DC power source, while the control signals are provided via the microcontroller. The actuator’s position is controlled through a PWM signal generated by the microcontroller. The LAC board then interprets these signals and modulates actuator extension accordingly by converting the pulse width into a proportional output voltage to drive the actuator. (Connection can be seen in Appendix F) [18]
User input is provided via the touchscreen interface/pin pad, where the desired pipetting volume is selected. The software maps a selected volume to a corresponding actuator position based on pre-established calibration data [17]. This ensures accurate displacement of pipette plunger, enabling the system to achieve volume delivery within the ISO 8655 [7] standards for accuracy (±1% of desired volume). The use of a 3D-printed mount and direct mechanical connection minimises movement of individual parts and ensures stability during actuation, critical for maintaining pipette precision when running multiple cycles.

### 3.6 LCD Screen and User Interface

The user interface is composed of two main I/O components: a touchscreen display and a numerical keypad. The touchscreen display is integrated with the microcontroller via a UART serial connection, utilizing the TX (transmission) and RX (reception) pins in the Elegoo Mega 2560 for data transfer (Appendix F). The display is 5 V, so it is powered through a regulated power source from the microcontroller to ensure a consistent power supply. The screen serves as the primary output device, providing real time feedback to the user when they are selecting volumes and specific output wells.
For user input, a number pad is connected to the microcontroller using digital logic pins. The keypad enables manual volume entry and operational commands, offering an alternative input method in scenarios where touchscreen interaction is less practical, like if the user wants tactile feedback with the inputs. Each key press is mapped to specific functions within the software, allowing the user to select operations and volumes for specific tasks (aspiration/dispensing).
Integration of both the touchscreen display and the physical keypad enhances accessibility and flexibility of our system, catering to users with varying levels of physical ability. Direct digital connections to the microcontroller and regulated 5 V power rails maintain signal integrity throughout the system, ensuring reliable and consistent communication and operation of user interface components even within a laboratory setting.
Figure 9 shows the screen sequence that the user must input. Colours have been implemented in accordance with accessibility requirements. [19] A full explanation can be found in Appendix H.

Figure 9: Screen Layout images

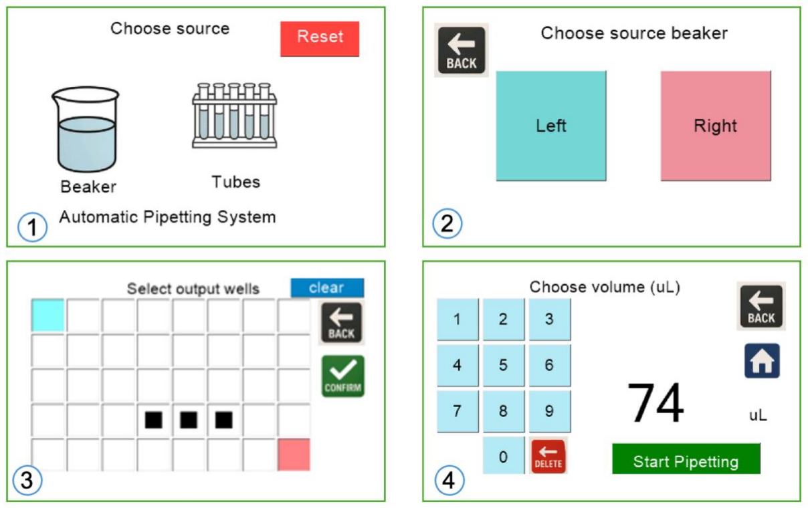
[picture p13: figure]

Note: User interface of the Automatic Pipetting System showing the step-by-step process: (1) selecting the source type (beaker or tubes), (2) choosing the source beaker (left or right), (3) selecting a single input well from a grid, and (4) setting the pipetting volume before starting the operation.

### 3.7 Software

The firmware is written in C++ and compiled in the Arduino IDE, providing low level control over the system’s mechanical and user interface components. The firmware implements a cartesian co-ordinate system, enabling precise, absolute position control across the axes. Upon startup, a homing routine is automatically executed, where each axis head towards mechanical end stop switches, establishing a reference zero position which is critical for accurate and repeatable operations.
For coordinated movements in the X-Y plane we use synchronized stepper motor pulses and linear trajectories, which are crucial for targeting wells and labware. The Z axis operates independently, enabling vertical pipetting actions without disrupting X-Y positions. The motion speed is controlled via adjustable microsecond step delays; these are tuned specifically for each axis to balance smooth motion and operational efficiency.
The touchscreen interface was developed using Nextion, a graphical tool for designing embedded user interfaces. While the graphical layer is designed via the software, the underlying control logic is written in a C-like language.
User selections on the screen trigger the transmission of control variables to the Arduino. These inputs are parsed to generate corresponding motor sequences, enabling the pipette's motion based on user commands.
Safety features are implemented directly in the software, preventing axis movement beyond physical limits and automatically terminating operations in the event of a homing failure. Additional safeguards are built into the touchscreen interface, such as restricting user input to valid volume ranges and preventing entries that are too large or too small.
The modular nature of the code allows for future extensions, including Bluetooth Low Energy modules, enabling system control via mobile applications, further enhancing accessibility for users with limited reach or dexterity. A full version of the code can be viewed in Appendix G.

### 3.8 Viability

There is strong evidence supporting the viability of this project, based on both market trends and user needs. Similar automated pipetting products already exist, indicating a proven market [20]; however, these are typically expensive and aimed at experienced researchers working in high-throughput laboratory environments. In contrast, our product is designed for a niche but underserved demographic: students and researchers with disabilities in STEM education. By offering a significantly lower-cost and more accessible solution, we address a key gap in the market. Our bill of materials in Appendix D highlights that the total material cost of one unit would be £483.53, this would allow us to be very competitive with systems that can cost upwards of £35 000 [5].

Currently, most laboratory accessibility tools focus on general-purpose accommodations rather than direct interaction with lab instruments. For example, products such as accessible lab benches, voice-activated lab software, and adjustable-height equipment aim to improve physical access to the workspace. Tools like tactile lab aids and screen-reader-compatible interfaces have also been developed to support visually impaired students [2] [3]. However, there are very few specialized tools that support fine-motor tasks like pipetting, which are often critical in chemistry and biology labs. The few assistive pipetting devices that do exist, such as ergonomic pipette aids or semi-automated dispensers, are generally designed for professionals and are not tailored for affordability or ease of learning.

Our solution is uniquely positioned to meet this gap by combining automation, low cost, and an education-focused user experience. Recent increases in the number of STEM students with disabilities, along with broader improvements in inclusivity and assistive technology in education, further support the relevance and potential popularity of our device [21]. Our approach combines affordability with a clear educational benefit, making it well-positioned for institutional adoption.

### 3.9 Scalability

The final design has been developed with scalability in mind, ensuring a smooth transition from prototype to mass production with minimal modifications. At its core, the system utilizes a commercially available 3D printer platform, which is already mass-produced and widely accessible—significantly reducing the complexity of scaling up. Custom components, including the redesigned pipette and associated electronics, will require separate manufacturing; however, both are suitable for scalable mass production through methods such as injection moulding, CNC machining, and automated PCB assembly.

One current limitation lies in the attachment point between the pipette and the printer arm, which lacks sufficient stability in its current iteration. Replacing this joint with welded metal components will enhance durability and ensure long-term reliability.

To ensure a successful transition to full-scale production and deployment, further work is needed to identify and mitigate potential risks. These include mechanical failures under continuous use, variability in component quality across batches, electronic reliability, and user safety considerations in educational settings. Addressing these risks early through rigorous testing, quality assurance protocols, and design refinements will be essential to maintaining system performance and user confidence at scale. Risks can be viewed in Appendix B.

Nevertheless, the system’s modular design supports straightforward scaling with only minor adjustments, making it a viable solution for broad educational deployment. Figure 10 outlines the remaining steps required before initiating mass production.

Figure 10: Flow chart representing manufacturing process

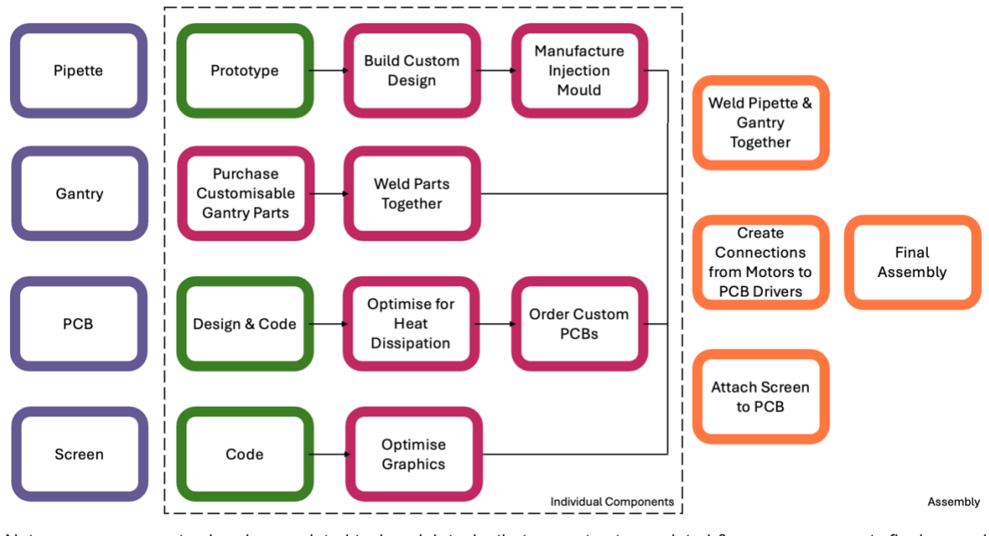
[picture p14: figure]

Note: green represents already completed tasks, pink tasks that are not yet completed & orange represents final assembly manufacturing

3.9.1 Electronics

The electronics are centred around a custom-designed PCB that integrates directly with the existing power and control systems of the 3D printer. While the current version is functional, there are opportunities to improve the layout, particularly by optimizing spacing between components. These adjustments would enhance heat dissipation, simplify servicing, and reduce the risk of interference during operation. From a manufacturing standpoint, the PCB is highly scalable and compatible with industry-standard processes such as PCB roller coating and automated pick-and-place assembly. For commercial deployment, the electronics must also comply with international standards. Specifically, the design must adhere to IEC 60446 for colour coding and identification and obtain CE certification and UKCA marking to meet regulatory requirements for safety and distribution [22] [23] [24].

3.9.2 Pipette & Holder

The current pipette is a functional prototype and has proven effective for initial testing. However, its 3D-printed construction presents significant challenges for large-scale production. The process is too time-consuming, and the resulting parts lack the durability and consistency required for reliable use in an educational setting. To address this, the pipette should be redesigned with manufacturability in mind. Potential approaches include using injection moulding or CNC machining to produce higher-quality components more efficiently. This redesign also presents an opportunity to improve the mechanical integration with the printer arm, potentially eliminating the need for a separate holder and simplifying the overall assembly.

3.9.3 Screen

The screen is coded using our own custom design. There are no issues with scaling the software or with mass producing the screen itself.

3.9.4 Gantry

The gantry has been repurposed from the 3d printer and should easily be scalable. There are certain design elements that may need to be slightly modified to fit the final design, such as the Z-axis limit switch arm.

## 4 Discussion

### 4.1 Design Evaluation

The automated micro pipetting system successfully fulfilled its core design requirement: allowing users with lacking fine motor control to successfully perform pipetting tasks independently and with reliable accuracy.

4.1.1 Evaluation Matrix

Requirements | Outcome | Evaluation | PSD [8] number reference
Accurately dispense between 100µL and 1mL within ±1% of the target volume | Able to calibrate pipette alone to complete this successfully, however actuator adds in extra uncertainty. | Partial success | 1.1
Chemical compatibility and safety with solutions such as buffer, salt and biological reagents. | All individual components, such as PLA filament, should be moderately chemical resistant. However, there have been no tests for extensive exposure. | Partial success | 1.2, 6.1, 9.3
Splash free dispensing due to controlled speed. | The actuator provides a controlled speed of liquid dispensing. | Success | 1.3
Contamination free use. | Not contaminated by coloured liquids between use, however chemical contamination between uses was not tested. | Partial success | 1.4
Simple operation for users of varying abilities. | According to user feedback 55% of users indicated that minimal instructions were necessary. | Success | 1.5, 3.1
Bluetooth control. | Due to feedback received it was determined that an integrated touchscreen/ touchpad would be more accessible for limited mobility. | Not successful | 1.6

Fit within lab bench of 75cm x 120-150cm. | The device is the able to fit on the lab bench, being 44cm x 44cm x 46.5cm. | Success | 2.1
Weight under 10kg in order to allow transportation. | The system is under 10kg and according to user feedback can be moved by one to two individuals depending on mobility limits. | Success | 2.4
Provides an adequate level of visual and auditory feedback. | The controls provide a level of visual feedback for users and minimal auditory feedback at the beginning and end of pipetting. (buzzer) | Success | 3.2
Minimises physical strain while both sitting and standing. | User feedback indicated that this minimises physical strain induced by using a manual micropipette. | Success | 3.3
Power consumption is compatible with mains power supply. | The power consumption of 24 watts is compatible with mains power supply due to a built-in adaptor on the gantry system. | Success | 4.2
Easy maintenance with detailed instructions and available parts. | Parts were sourced locally, where possible and instructions are provided on how to use the system. | Success | 7.1
Affordability should be under £600 to compare with similar equipment. | The total cost of the product was £483.53. This is well below the £600 target and can be optimised further with mass production (Appendix D) | Success | 8.1
Accessible for as wide a range of users as possible. | Depending on the user’s disability this product does provide a more accessible solution to micro pipetting according to user feedback. | Partial Success | 9.5

Table 1. Table of the Evaluation of the requirements against the PSD.

4.1.2 Testing

The pipetting system was tested for both volumetric accuracy and cross-contamination. To assess accuracy, the system was programmed to dispense target volumes ranging from 30 to 100 µL. The dispensed volumes from the automatic pipetting system were quantitively compared to the dispensed volumes from a manual micropipette. It was observed that as volumes decreases, accuracy and precision decreased as volumes became more difficult to dispense [25].
Across the tested range, the system consistently achieve accuracy within a +/- 1% tolerance. Cross contamination was evaluated qualitatively. Between dispense cycles, dyed liquids were first run through the system, after each cycle the pipette tip was replaced, and a clear liquid was dispensed. There were no visual traces of the dye observed. For a quantitative check, the absorbance of the sample could have been measured using a spectrophotometer [26]. An absorbance closer to zero would have been achieved after clear liquid was dispensed.

Pipette

- Target volumes ranging for 100 µL and 1 mL are set

- Liquid is dispensed and output is measured using a scale
- The actual volume against the target volume is recorded
- Pipette is calibrated to minimize error
- Dyed liquids are run through the system
- Pipette tip is removed and replaced
- Cycle is repeated and run with clear liquid to confirm no carryover from previous cycle

The system was programmed to dispense volumes between 100 µL and 1 mL and was verified to be within a tolerance of ±1%. Tests were conducted with various inorganic chemicals and dispensing speed was assessed by observing liquid’s flow rate and splash.

Gantry System

- Measure positional accuracy by comparing actual position to target position
- Record deviation from target positions for each axis
- Test for repeatability by programming gantry to return to a target point over multiple cycles
- Test for the speed of movement by using the micros() Arduino function and measuring the distance
The accuracy, precision and repeatability of movements with the gantry were assessed across multiple cycles. Tests were conducted under standard lab conditions (25°C, 298K, 1 atm) with minimal positional error.

Display

- Confirm the default screen is displayed when connected to Arduino
- Load a sample GUI via a microSD card and check the interface displays correctly
- Test accuracy of all GUI elements for touchscreen accuracy by observing output responses
- Qualitatively inspect the display to ensure there is uniformity in the pixel light intensity
- Run the display for several hours to check for stability, overheating or glitches

4.1.3 User Testing and Feedback

Due to the limited time after completion of the project only a 20 people were able to participate in testing of the product. This also made it difficult to find many participants with physical disabilities. If there was more time after finalising the product, the group would’ve ensured a larger sample size, that was representative of the target market, was used.

To compensate for the lack of representation in the sample, finger resistance bands were used on the able-bodied participants to limit their mobility and dexterity in the hands. It was also confirmed by our disability consultant (an engineer with chronic pains, muscles spasms and hand tremors) that this was an adequate representation of what limited mobility can feel like for some disabilities.

Overall, the feedback from participants was positive (Appendix J), with 90% of participants rating the aesthetics of the design 4-5. This suggests that most people thought the product would fit seamlessly into a lab environment. However, there was a range of results for the portability of the design - 45% of participants thought the machine would be easy to move under less intense periods of limited mobility. 100% of participants found no difference in difficulty between dispensing and aspirating the liquid. Further comments repeatedly suggested either a larger touchscreen or bigger touch icons were used as they found it slightly more difficult to navigate the user interface. Some disabled participants also suggested that tactile feedback from buttons or a keypad would have been preferred.

4.1.4 Future improvements to design

With more project time and resources, we would implement the following:

Improvement | Outcome
Add a mechanical or servo-driven pipette tip ejection system that presses the side button of the pipette | Our current prototype lacks a tip ejection mechanism, requiring manual removal. Incorporating a linear actuator or servo to press the side button would enable hands-free ejection. This significantly improves accessibility for users with limited dexterity, ensures biosafety by reducing contamination risk, and aligns with good laboratory practice (GLP) standards.
Design a compact, integrated tip disposal unit (e.g. mini sharps bin) | A small, enclosed container positioned adjacent to the pipette holder would allow automatic ejection of tips directly into a safe place. This promotes hygienic disposal, prevents biohazard exposure, and complies with lab waste management protocols. The bin should be removable for easy emptying and should be autoclavable or disinfect able.
Replace 3D-printed structural components with CNC-machined or injection-moulded parts for final-stage manufacturing | Transitioning to more robust manufacturing methods in large-scale production improves structural integrity, thermal and chemical resistance, and aesthetic finish. Injection moulding offers lower per-unit cost at scale, while CNC machining provides tighter tolerances and durability for moving parts.
Include a removable spill tray or hydrophobic barrier beneath the pipette tip | This protects critical electronics from liquid spills or pipette drips. A removable tray facilitates cleaning, while a hydrophobic coating or physical splash guard further reduces the risk of short-circuiting, enhancing device longevity and electrical safety.
Develop a fully enclosed, modular outer casing | Enclosing wires and electronics in a custom-fitted case improves user safety, reduces the chance of accidental disconnections or electrostatic discharge, and gives the system a professional, medical-grade appearance. Modular design allows future subsystems (e.g., automated tip racks, wireless controls) to be added without redesigning the full enclosure.
Implement noise- and vibration-reduction strategies | Our Motor and gantry systems currently generate significant noise. Damping techniques would reduce mechanical vibration and acoustic interference, enhancing comfort in quiet labs and increasing pipetting precision.
Upgrade UI system: larger display, tactile feedback, and alternative input methods | Replace the current small touchscreen with a larger capacitive display to improve visibility and touch accuracy. Redesign the UI to bigger icons, clearer layouts, and colour-contrast options. Incorporate tactile and/or auditory feedback to support users with visual impairments or sensory sensitivities.
Integrate a high-throughput batch pipetting mode | Currently, each pipetting action must be triggered individually. By introducing programmable sequences throughput can be significantly increased. This would be useful in repetitive workflows.

Table 2. Table of Future Improvements

### 4.2 Project Reflection

4.2.1 Core Values

From the beginning of the project, we wanted to create a safe and welcoming environment for all members of the group to respectfully and unapologetically share their opinions of our work. This made us all very comfortable with having our voices heard and also receptive to constructive criticisms. When members of our group had conflicting ideas, we were encouraged to critique each other and debate on what the next steps in our project should be. In addition to this, democratic votes were regularly taken via polls to ensure the majority of members in the group were happy with decisions being made. Even when polls were taken, we were all still comfortable further debating our ideas to make sure the best possible decisions were made for the future of our project. This was extremely beneficial to our as our consistent collaborative efforts created even better ideas than what we initially had.

It was imperative that each member in our group was clearly communicated with and understood the different stages of our project. During our initial design ideas phase, we would all draw rough sketches of how we interpreted and idea from another member of the group. This allowed us to clarify the ideas of our members and ensured we had to correct impression of what they were saying. By doing this, we were able to make well-informed decisions on the future of our project. When we all drew sketches of design ideas, it allowed for more effective communication of member’s individual perspectives which we would later bring together to make a more interesting product. This created a lot more cognitive diversity in our group which is essential for any successful group project.

4.2.2 Division of the Workload

We all initially discussed our strengths and weaknesses with regards to the skills required for our group project. We believed that it was important to align tasks with team members’ competencies to maintain high standards of work. The aim of our project is to increase accessibility for disabled people in the lab, meaning that it was important for us to reach out to as many people as possible from these communities to get their perspective on our designs. Because of this, all members of our group were initially assigned outreach and field research tasks to gather as much information as possible before the design work commenced. After this, we were divided into subgroups based on our interests, the demand of specific design components and the urgency for when things needed to be completed. For example, initially more team members worked on the PSD due to its urgency - this later transitioned to more team members working on the mechanics and electronics of the gantry system as this was a main component of our design. The subgroups that were initially set were fluid and not at all homogenous. We made sure that when work had been completed, team members moved to other areas of the projected as and when they were needed.

4.2.3 Means of Communication

Our WhatsApp group and Teams were the main platforms used to maintain regular communication with other team members. We would post video updates to document the progression of different components of the design so that all members of the group were up to date with the status of the project. There were also sub-WhatsApp groups where more specific conversations were had, pertaining to the different components of this design. This allowed us to easily compartmentalize the information and progression related to different parts of the project to avoid confusion. We would also have meetings throughout the year via WhatsApp, Microsoft Teams, or in person. The minutes of the meetings were recorded on OneNote so we could easily refer back to what was discussed. As well as this, we also used Google Docs, Word and Canva to easily integrate individual’s work.

4.2.4 Improvements

There was a very amicable and encouraging team dynamic that only bolstered very productive work for the duration of the project. However, there are always points of improvement that need to be considered in the future projects we all undertake. Although we communicated quite frequently on other platforms, there should have been a more regular schedule for weekly or biweekly in-person meetings to discuss the status of the group work. More in-person meetings may have led to more effective communication and allowed for clarification in case anything was misinterpreted online. For the meeting that we did have, recordings should have been in case the minutes on OneNote were unclear or lacked detail. To better organize meetings in future projects we aim to incorporate other platforms that better facilitate scheduling, such as Slack or Monday.

### 4.3 Conclusion

In conclusion, the automated micro pipetting system successfully achieved its core aim: enabling individuals with limited dexterity to independently and accurately perform pipetting tasks, thereby enhancing accessibility in laboratory environments. While some features remain in development or require refinement, such as tip ejection and expanded user feedback, the overall system met key design and performance criteria, including accuracy, usability, and affordability. Through iterative testing, user input, and thoughtful design, the project demonstrated a viable and scalable assistive technology solution. This work not only contributes a practical tool for inclusive education and research but also highlights the broader value of human-centered design in promoting equity within STEM fields.

## References

1. Kirk-Wade E. commonslibrary.parliament.uk . House of Commons; 2024 Oct [cited 2024 Nov 22]. Available from: commonslibrary.parliament.uk
2. Duder BS. Accessible Light Microscope for Students with Mobility and Visual Impairments [Internet]. Purdue University; 2006 [cited 2025 Jun 17]. Available from: https://web.ics.purdue.edu/~bsd/papers/duerstock_2006.html
3. GmbH B. GS 39 Glass Bathroom Scale For Sale [Internet]. [cited 2025 Jun 17]. Available from: https://www.beurer.com/uk/p/74400/
4. Equality Act Compliant Lab Furniture [Internet]. 2023 [cited 2025 Jun 17]. Available from: https://apmg.co.uk/laboratory-furniture/desks/adjustable-height/
5. AG TT. Tecan D300E Digital Dispenser [Internet]. [cited 2025 Jun 17]. Available from: https://lifesciences.tecan.com/products/liquid_handling_and_automation/tecan_d300e_digital_dispenser
6. Dragonfly discovery [Internet]. [cited 2025 Feb 12]. Available from: https://www.sptlabtech.com/products/dragonfly/dragonfly-discovery
7. DAPP Group F (2025) Product Specification Document, Imperial College London Bioengineering Students
8. [Internet]. [cited 2025 Jun 17]. Available from: https://www.iso.org/obp/ui/#iso:std:iso:8655:-1:ed-2:v1:en
9. Temperature [Internet]. [cited 2025 Jun 17]. Available from: https://www.imperial.ac.uk/estates-facilities/buildings/procedures/temperature/
10. Creality Ender 3 3D printer: 220*220*250mm [Internet]. [cited 2025 Jun 17]. Available from: https://www.crealityofficial.co.uk/products/official-creality-ender-3-3d-printer
11. Pololu - A4988 Stepper Motor Driver Carrier [Internet]. [cited 2025 Jun 17]. Available from: https://www.pololu.com/product/1182
12. Creality 3D 42-26 Stepper Motor [Internet]. [cited 2025 Jun 17]. Available from: https://www.3dprima.co.uk/creality/creality-3d-42-26-stepper-motor-12328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
13. Ranakoti L, Gangil B, Mishra SK, Singh T, Sharma S, Ilyas RA, et al. Critical review on polylactic acid: Properties, structure, processing, biocomposites, and
nanocomposites [Internet]. U.S. National Library of Medicine; 2022 [cited 2025 Jun 17]. Available from: https://pmc.ncbi.nlm.nih.gov/articles/PMC9228835/?utm
14. Ranakoti L, Gangil B, Mishra SK, Singh T, Sharma S, Ilyas RA, et al. Critical review on polylactic acid: Properties, structure, processing, biocomposites, and nanocomposites [Internet]. U.S. National Library of Medicine; 2022 [cited 2025 Jun 17]. Available from: https://pmc.ncbi.nlm.nih.gov/articles/PMC9228835/?utm
15. Casalini T, Rossi F, Castrovinci A, Perale G. A perspective on polylactic acid-based polymers use for nanoparticles synthesis and applications [Internet]. U.S. National Library of Medicine; 2019 [cited 2025 Jun 17]. Available from: https://pmc.ncbi.nlm.nih.gov/articles/PMC6797553/?utm
16. Labo Modern [Internet]. ScriLabware; [cited 2025 Jun 17]. Available from: https://www.labomoderne.com/catalogues/scilabware_catalogue.pdf
17. Brennan MD, Bokhari FF, Eddington DT. Open design 3D-printable adjustable Micropipette that meets the ISO standard for accuracy [Internet]. Multidisciplinary Digital Publishing Institute; 2018 [cited 2025 Jun 17]. Available from: https://www.mdpi.com/2072-666X/9/4/191
18. Home [Internet]. [cited 2025 Jun 17]. Available from: https://www.actuonix.com/pq12-p
19. Deane K. Final Report - Access All Areas in Labs Project. 2023.
20. Labtech S. Industry report: The State of Automated Pipetting 2022 [Internet]. SPT Labtech Ltd; 2022 [cited 2025 Jun 17]. Available from: https://www.sptlabtech.com/blog/the-state-of-automated-pipetting-2022?utm_
21. Srivastava A, Deshmukh R. Assistive Technology For Students With Learning Disabilities Market By Product Type (Hardware and Software), Condition (Processing Deficits, Processing Deficits Autism, Dyslexia, Dyscalculia, Dysgraphia, and Others), and End User (Specialized Schools, Universities, and Others): Global Opportunity Analysis and Industry Forecast, 2021-2030. 2021 Jul.
22. International Electrotechnical Commission.; 2010.
23. CE marking [Internet]. Department for Business and Trade and Department for Business, Energy & Industrial Strategy; 2012 [cited 2025 Jun 17]. Available from: https://www.gov.uk/guidance/ce-marking
24. Using the UKCA marking [Internet]. Department for Business and Trade; 2020 [cited 2025 May 1]. Available from: https://www.gov.uk/guidance/using-the-ukca-marking
25. Good laboratory [Internet]. Thermo Fisher; [cited 2025 Jun 17]. Available from: https://assets.thermofisher.com/TFS-Assets/LPD/manuals/Good-Lab-Pipetting-Guide-1517630-01-Brochure-EN.pdf
26. Spectrophotometry [Internet]. [cited 2025 Jun 17]. Available from: https://www.sciencedirect.com/topics/chemical-engineering/spectrophotometr

## Appendices

## Appendix A – Project Management

Our team consisted of 9 2nd year Molecular Bioengineering students. and was supervised by Dr Ian Radcliffe. Responsibilities were distributed based on individual group members’ personal interests and skills. The team was initially divided into sub-groups to manage different components of the design: pipette, electronics, gantry mechanics and CAD. Each sub-group provided regular updates during meetings held via Microsoft Teams, with meeting minutes recorded on a shared OneNote notebook and communication was maintained through WhatsApp.

As a collective, the group generated initial design ideas that were eventually refined until a final concept was a agreed upon. As apart of this process, all members took part in initial research and data collection – liaising with disability officers and lab technicians to get their input on our ideas so informed decision could be made on the direction of the project.

The distribution of roles across the group are as follows:
All group members contributed to the PSD, presentation, poster and prototyping.

Ben Jones
- PSD Editor
- CAD Technician
- Final Report Writer

Jenna du Preez – Scribe
- PSD Editor
- 3D printing
- Poster content

Kailin Wang
- Gantry Assembler

Leonardo Grimaldi

Sheena Ling – Procurement Manager
- Poster writer and designer
- Final design drawings
- CAD Technician

Sumaiyah Zaman
- PSD Editor
- Report Writer
- 3D printing

Tayeb Tadlaoui
- Presentation Video Editor
- LCD Touchscreen
Developer
- Arduino code Developer

Yasmine Marenzi – Project Manager
- Pipette and Actuator
Manufacturer
- CAD and 3D printing
- Arduino Code Developer
- Gantry Manufacturer
- Arduino code Developer

Sean Obi
- Final Report Writer
- Electronics Leader
- Arduino code Developer
- Gantry Assembler
- User-testing coordinator

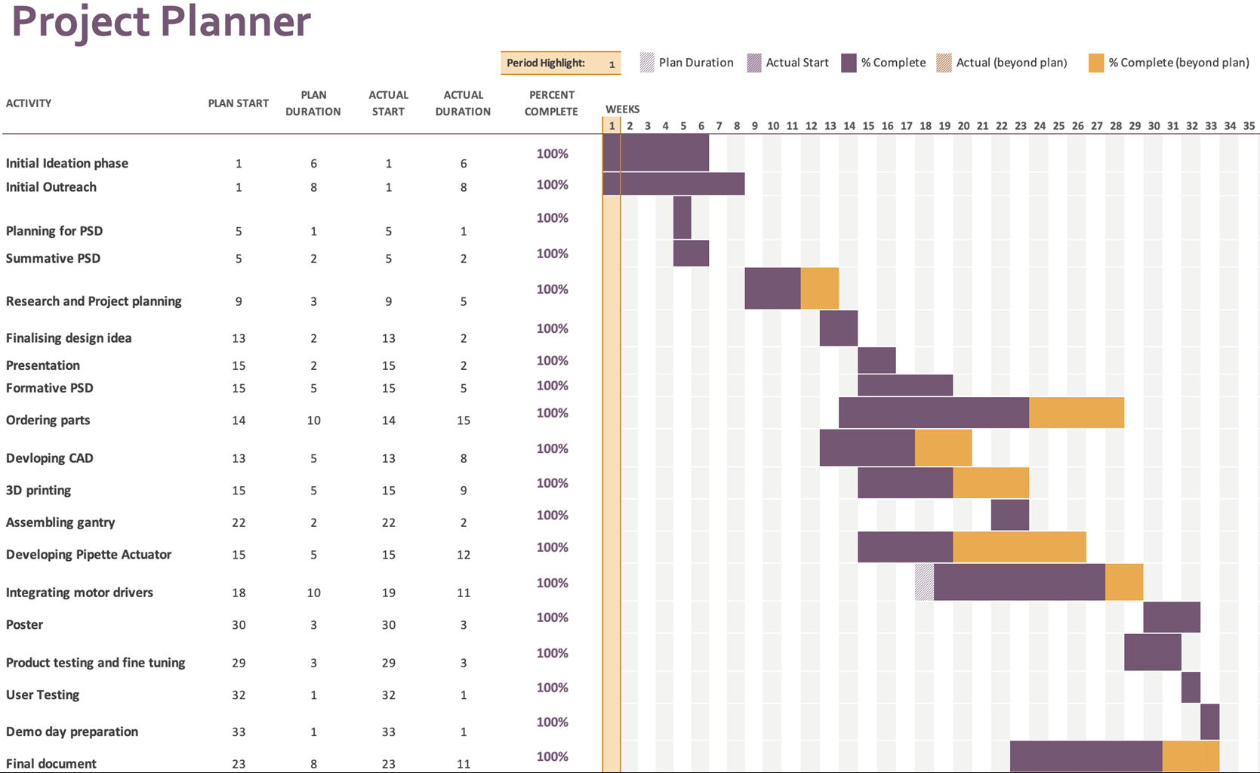
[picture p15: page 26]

Figure A.1: Gant Chart

## Appendix B – Risk Management

Potential risks or causes of failure in our design were analysed and rated based on their Severity (S), probability of Occurrence (O) and Detection (D). Each of these 3 components to the risk were evaluated on a scale of 1-10. The 3 numbers are multiplied to achieve the Risk Priority Number (RPN) to define the level of risk posed by particular parts of the design. A critical RPN threshold of 75 was chosen and preventing measure were put in place to ensure the RPN stays well below the threshold.

S – Severity

Rating S | Criteria: Severity of effect | Consequence | Treatment
10 | Death | - | -
9 | Quadriplegia | Life-long medical care necessary /
coma / permanent damage | Hospital stay

8

Amputations, | paraplegia, | blindness, | deafness,
traumatic brain injury (severe), fourth-degree burns

Life-long medical care necessary /
coma / permanent damage | Hospital stay

7

Complex fractures, open fracture, inner injuries,
traumatic brain injury (severe), third-degree burns | Permanent damage possible | Hospital stay
| Gash, fractures, torn muscles, articular cartilage
6 | injury, traumatic brain injury (moderate), second- | Permanent damage possible | Hospital stay
| degree burns
| Gash, fractures, torn muscles, articular cartilage
5

injury, traumatic brain injury (mild), second-degree burns

Reversible injury | Hospital stay or ambulant treatment

4

Severe cuts, severe scratches, severe contusions,

| strains, first-degree burns | Reversible injury | Ambulant treatment or self-
| | | treatment
3 | Minor cuts, minor scratches, minor contusions, stiff
| muscles, tension, blisters, excoriations, sickness, first-
| degree burns | Discomfort during application up to
| | three days after application | Self-treatment
2 | Slight sickness, pressure marks | Discomfort | -
1 | No harm | - | -

O – Occurrence

Rating O | Criteria: Probability of occurrence
10 | Occurs or may occur very likely during every use of the session
9 | Occurs or may occur likely during every use of the session
8 | Occurs in 1 of 5 sessions (less than once a day)
7 | Occurs in 1 of 10 sessions (less than once a day)
6 | Occurs in 1 of 50 sessions (less than once half a month)
5 | Occurs in 1 of 100 sessions (less than once a month)
4 | Occurs in 1 of 500 sessions (less than once half a year)
3 | Occurs in 1 of 1000 sessions (less than once per year)
2 | Occurrence very unlikely
1 | Occurrence nearly impossible

D – Detection

Rating D | Criteria: Likelihood of detection by design control
10 | No chance of detection
9 | Very remote chance of detection
8 | Remote chance of detection
7 | Very low chance of detection by indirect methods (hardware or software)
6 | Low chance of detection by indirect methods (hardware or software)
5 | Moderate chance of detection by indirect methods (hardware or software)
4 | High chance of detection by indirect methods (hardware or software)
3 | High chance of detection by direct or indirect methods (hardware/software)
2 | Direct and indirect detection: Hardware or software
1 | Direct detection: Hardware or safe software (category 4, performance level e)

Risk Analysis
Assembly | Failure & Effect | S1 | O1 | D1 | RPN before
Preventing measures | S2 | O2 | D2 | RPN
after
Pipetting Mechanism | The pipette actuator is incorrectly calibrated and leads to incorrect volume dispensed. Risks experimental error and could lead to liquid spillage, damaging electronics. | 2 | 10 | 8 | 160

Pipetting mechanism should be calibrated
before integration into system. Software-driven calibration can also be implemented for the actuator. A test dispense feature should be implemented before a new aliquoting cycle.
1 | 2 | 2 | 4

Touchscreen
Interface

Graphical distortions
(flickering/flashing) on the screen may trigger disabilities (epilepsy) and confuse the user with
regards to functionality.
5 | 5 | 3 | 75

Design a user interface with stable refresh rate and bigger icons. Avoid any flashing animations and consult the accessibility standards in WCAG during the UI design.

1 | 2 | 3 | 6

Touchscreen
Lag

It is possible to misinterpret the touch icons when the response is delayed. This increases the time taken to carry out
experiments and can increase the fatigue or stress put on the user.
4 | 7 | 5 | 140

Add a keypad of buttons that allow users to
operate the device without the need for the
touchscreen. This can be used as a
failsafe. | 2 | 7 | 5 | 70

Gantry
Collision

Moving gantry system may
collide with the frame or nearby objects (users’ hands). This can potentially damage different mechanical components or
cause user injury.
8 | 3 | 6 | 144

Limit switches are added to act as physical and logical boundaries in firmware that prevent the overextension of the gantry. The end-stop sensors in the limit switches will halt the movement of the gantry and trigger a return-to-origin sequence.

2 | 2 | 2 | 8

Pipette tip
handling

Caused by residual fluid or reuse of pipette tips, leading to cross contamination of samples which can compromise the integrity of results and the sample purity.

1 | 8 | 9 | 72

Mandate single-use pipette tips and implement training for the user. Add visual prompts in the UI for manual tip replacements. In future developments, add automatic tip ejection.

1 | 2 | 9 | 18

Tip
attachment
mechanism

Pipette tip fails to attach securely, causing tip to fall off during aspiration or dispensing, contaminating samples and
reducing experimental reliability.
6 | 6 | 4 | 144

Implement a mechanical locking system to secure the tip and verify attachment with a load sensor or pressure check in software. Instruct users to visually inspect tip placement before use.

3 | 2 | 2 | 12
Long | term
actuator
wear

After repeated cycles, the linear actuator may wear out, reducing precision or causing erratic movements, risking sample loss or injury.

4 | 4 | 5 | 80

Use an actuator rated for high cycle life. Include periodic maintenance guidelines. Optionally allow users to replace actuator easily via a modular design.

2 | 2 | 5 | 20

Internal
electronics
overheating
(Fire hazard)

Prolonged use of the device can lead to overheating of the Arduino and the motor drivers. When components exceed safe operating temperatures this can lead to permanent damage of components which inhibits the functionality and consequently reduces the lifespan of the product. If ignition temperatures are reached this can cause melting, smoking or even fires.

9 | 3 | 5 | 135

Ensure experiments are conducted in a well-ventilated room for better air circulation. Add heat sinks to passively cool the electrical components by releasing the excess heat to the surroundings. Regularly use freeze spray for a rapid, local decrease in temperature on the circuit board.

1 | 3 | 5 | 15

Overvoltage
(Mains)

If mains power (230V AC) is improperly connected or
regulated it can exceed the safe operating voltage for low-voltage DC components, causing instant failure or even a fire risk in the device.
9 | 2 | 7 | 126

Use a certified external regulated adapted (e.g. 12 V) and step down the voltage to 5 V using buck converters. Add a fuse to break the circuit when current gets too high. Instead, use bench top power supplies for each motor driver – allows for precise voltage and current control.
Overvoltage
(Bench top
power
supply)

Incorrect voltage or current setting on the external power supply may result in overvoltage which could damages the
electrical components or pose a
5 | 8 | 1 | 40

Train users to verify voltage and current settings before use. Cover unused outputs with insulating caps. Add a fuse to break the circuit if current gets to high. Label all

5 | 4 | 1 | 20

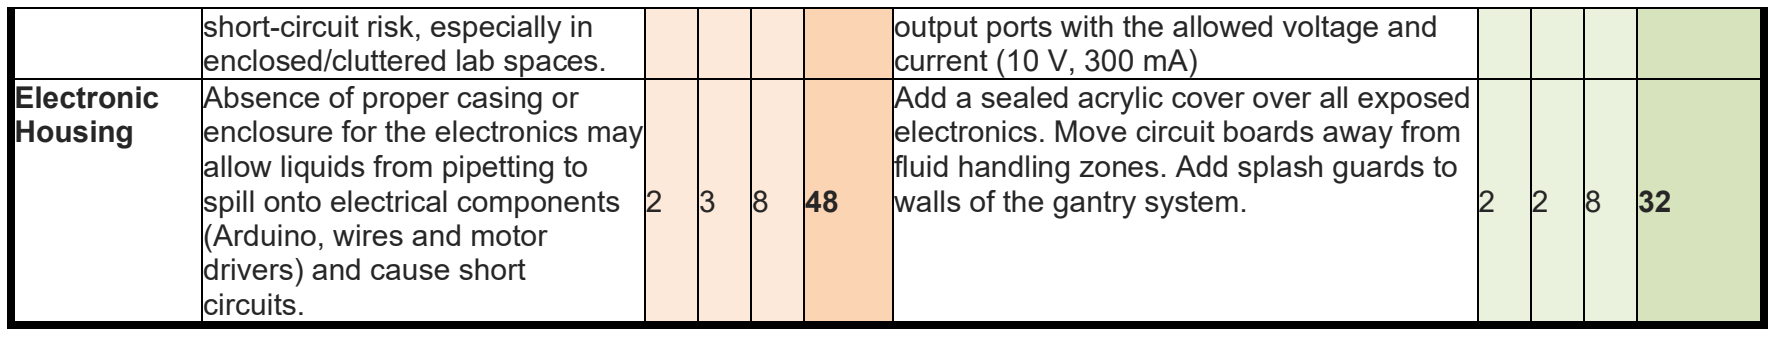
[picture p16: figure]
short-circuit risk, especially in enclosed/cluttered lab spaces.; current (10 V, 300 mA); Electronic Housing; Absence of proper casing or enclosure for the electronics may allow liquids from pipetting to spill onto electrical components (Arduino, wires and motor drivers) and cause short circuits.; walls of the gantry system.

output ports with the allowed voltage and

Add a sealed acrylic cover over all exposed electronics. Move circuit boards away from fluid handling zones. Add splash guards to

Table B.1: Table of Risk assessments

## Appendix C – Ethics

- Ethical considerations

Ethical considerations were an integral part of the design and development of our Automated Micro pipetting System, given the device’s intended purpose of improving accessibility for individuals with physical disabilities. Our aim was not only to create a technically functional device, but also to ensure that it aligns with broader principles of inclusivity, respect for users, and responsible engineering practice.

- Honesty

Throughout our project, we ensured that all data, research, surveys, and technical limitations were communicated truthfully, especially when reporting the system's accuracy and limitations in our final testing. (Add an example after user testing done)

- Scientific Integrity

All literature used during the development of our kit was thoroughly cited and acknowledged in our final report. We upheld academic integrity by giving full credit to all open-source designs incorporated into our project, including the 3D-printed micropipette model and the Ender 3 gantry system. Any ideas, data, or designs that informed or inspired our work were appropriately referenced to ensure transparency and respect for intellectual property.

- Legality

We ensured the design complied with standard safety guidelines, any images or videos used did not violate copyright or licensing laws and used only legal sources for components and code. To be released onto the market, our Automated Micro pipetting System would need to be registered with the MHRA in compliance with UK Medical Devices Regulations. (Register medical devices to place on the market - GOV.UK) (https://www.gov.uk/guidance/register-medical-devices-to-place-on-the-market)

- Respecting Intellectual Property

We ensured any sample code, CAD models, or mechanical parts adhered to licensing agreements. For example, the open-source micropipette we adopted complies with ISO standards and its licensing terms.

- Respect for Colleagues

To ensure fairness and inclusivity within the team, tasks were divided as equally as possible. Open communication was encouraged through regular meetings, polls, and discussions, creating a respectful environment where all opinions could be shared and constructive feedback welcomed. Group decisions were made collaboratively, with polls conducted via WhatsApp and Teams, and majority votes guiding outcomes. Personal commitments, such as health needs, were accommodated, and members supported one another during challenging periods.

- Non-Discrimination

Through research and expert consultation, we identified hand tremors and dexterity impairments as key barriers to equal participation in manual micro pipetting. Our design prioritized inclusivity by creating a system accessible to users with varied physical abilities, including limited dexterity, tremors, or reduced hand strength. We followed established accessibility guidelines and used inclusive language to ensure no user is excluded or disadvantaged based on physical ability. This reflects our ethical commitment to non-discrimination, removing barriers to fair access, and enabling all individuals to participate fully in laboratory work.

- Privacy and Confidentiality

User testing, feedback and survey responses were fully anonymized to protect participants’ identities. No personal data was collected or stored, and all feedback was treated confidentially. Informed consent was obtained where applicable, ensuring ethical handling of all user interactions.

- Environment & Sustainability

Environmental impact and sustainability were core considerations throughout the design and development of our Automated Micro pipetting System. Our goal was to create an accessible, functional device while actively minimizing energy consumption, material waste, and the system’s overall environmental footprint.
Various structural components, including the pipette mount and adaptors, were 3D printed using PLA, a biodegradable material under industrial composting conditions. We optimized print settings such as infill percentage and layer height to reduce filament use without compromising durability. Multiple parts were printed simultaneously in batch jobs to reduce energy consumption from the printer. Failed prints were disposed of responsibly and recycled where possible.
Electronic components such as the Elegoo Mega 2560, motor drivers, and actuators were sourced from UK-based or domestic suppliers when available to reduce carbon emissions associated with long-distance shipping. Orders were combined to reduce packaging waste and delivery frequency.
To reduce future waste, the system was designed with modularity and repairability in mind. Components such as the pipette tip holder, linear actuators, and end stop switches can be individually replaced or upgraded without discarding the full unit. This extends the product’s lifespan and supports a circular usage model. Where feasible, we selected reusable or recyclable materials and adhered to WEEE guidelines for responsible e-waste management.
The device also considered sustainability during use. Its lightweight frame and efficient actuator system limit unnecessary energy consumption. Used micropipette tips are intended to be disposed of according to standard lab safety and environmental waste protocols, including sharps bin use where relevant.

## Appendix D - Bill of Materials

Component | Manufacturer Part Number (MPN) | Description | Manufactur er | Supplier s | Un its | Unit Cost /£ | Tot al Cos t | Remarks
Electronics (Arduino, PCB) | EL-CB-003 | Elegoo Mega 2560 R3 Controller Board | Elegoo | Amazon | 1 | 21.98 | 21. 98 | Arduino Mega Compatible
| N/A | 2-Layer Bare Rigid Printed Circuit Board | JLCPCB | JLCPCB | 1 | 99.22 | 99. 22 | Customised PCB board
| PPTC081LFB N-RC | CONN HDR 8POS 0,.1 TIN PCB | DigiKey | DigiKey | 19 | 0.496 | 9.4 2 | /
| 277-1258-ND | Term Blk 2Pos Side Entry 5mm PCB | DigiKey | DigiKey | 1 | 1.2 | 1.2 0 | 2-Position Side-Entry Terminal Block, 5.08mm Pitch
| 552440 | LM2596 DC-DC Switching Adjustable Step Down Voltage Regulator Module 4.5 V-40V | Switch Electronics | Switch Electroni cs | 5 | 1.95 | 9.7 5 | /
| D-A4988 | Control Stepper Motor with A4988 Driver Module and Arduino | Oosznest | Oosznest | 4 | 4.52 | 18. 08 | Max output of 35 V at +/- 1.5A, with 5 step revolutions of full, half, quarter step, etc. Built in potentiometer.
Gantry System | Ender-3 | Creality Ender-3 3D Printer | Creality | Creality Official Store | 1 | 139.00 139 | .00 | Includes frame, motion system, power supply, control system, LCD interface and wiring
Pipette | 7324892696 15 | 10 Pack 3ml/3cc Syringe | GSSFASHI ON | Amazon | 1 | 5.48 | 5.4 8 | Made of PLA, PC and PE. Dimension s: 8.7L x 2.5W cm.
| 6024512342 | Sourcingmap M3 x 35mm Carbon Steel | RC Screws | Amazon | 1 | 6.59 | 6.5 | Grade Rating: Class 10.9

| | Full Thread Hex Socket Cap Head Screws Bolt 25 Pcs
| B08HL9VVHX | M3 Hex Full Nut - A2 Stainless Steel (20 pcs) | Ascot City | Amazon | 1 | 6.49 | 6.4 9 | DIN 934
| LC022D10M | Standard Compression Spring | Lee Spring | Lee Spring | 2 | 4.24 | 8.4 8 | /
| E-F-160049 | Kynar Luer, Female Luer Lock to 5/32" (4.0mm) ID Tube | Eoxshop | Eoxshop | 1 | 27.36 | 27. 36 | Meets Requirements for USP Class VI, California Prop. 65, ISO 594
Screen | 2966836380 09 | Nextion 4.3" HMI Display Basic NX4827T 043 LCD-TFT Resistive Touch Screen 480x272 | SONOFF STORE | Ebay | 1 | 52.79 | 52. 79 | Compatible with NEXTION editing software
| B0DRNNH8J R | 32GB Micro SD Card, Memory Card with SD Adapter | PHISON ELECTRONI CS CORP | Amazon | 1 | 11.98 | 11. 98 | /
Actuator | RB-Fir-121 | Actuonix Linear Actuator Control Board | RobotShop | RobotSh op | 1 | 10.01 | 10. 01 | /
| 2595 | Kitronik Linear Acuator Micro Servo Kit | Kitronik | Kitronik | 1 | 18.95 | 18. 95 | /
Maintenance/Tes ting | 7414163403 58 | 4 Pack Hand Exerciser Grip Strengthener for Arthritis | PORTHOLI C | Amazon | 1 | 13.98 | 13. 98 | /
| M090409 | Motip Freezer Electronic Spray - 360ml | MOTIP | Amazon | 1 | 15.28 | 15. 28 | Non-flammable
| 5010305061 236 | Loctite Universal Strong All Purpose Super Glue | Loctite | Amazon | 1 | 7.49 | 7.4 9 | /
Total Cost (£) | 483.53
Table D.1: Bill of material

## Appendix E – Nomenclature

Actuator – A component that moves or controls a mechanism or system (e.g., applies force).
Arduino – An open-source electronics platform based on easy-to-use hardware and software, used in embedded systems development.
Buzzer – An electronic component that emits a sound signal, typically used for auditory feedback.
CAD – Computer-Aided Design.
CNC – Computer Numerical Control, a manufacturing process that uses computerized controls to operate machine tools.
Chemical Compatibility – The ability of a material or system to resist chemical degradation when exposed to various substances.
Display (Touchscreen / Touchpad) – A display that also serves as an input device by responding to touch.
FDM – Fused Deposition Modelling, a 3D printing technique.
GLP – Good Laboratory Practice, a set of principles intended to ensure the quality and integrity of non-clinical laboratory studies.
Gantry System – A mechanical structure that allows controlled movement along multiple axes (X, Y, Z).
GUI – Graphical User Interface.
I/O – Input / Output, referring to the transmission of data.
IDE – Integrated Development Environment.
IEC – International Electrotechnical Commission.
ISO – International Organization for Standardization.
LCD – Liquid Crystal Display.
Labware – Reusable or disposable items used in laboratories (e.g., beakers, tubes, pipette tips).
Limit Switch – A sensor that signals when a component has reached the end of its range of movement.
LAC – Linear Actuator Control.
mL (Millilitre) – One-thousandth of a litre (10⁻³ litres), standard unit of liquid volume in laboratory contexts.
Microlitre (µL) – One-millionth of a litre (10⁻⁶ litres), used for measuring small liquid volumes in labs.
Micros() – An Arduino function that returns the number of microseconds since the board began running the current program.
PCB – Printed Circuit Board.
PLA – Polylactic Acid, a biodegradable thermoplastic used in 3D printing.
PWM – Pulse Width Modulation.
Spectrophotometer – An analytical instrument used to measure the amount of light absorbed by a sample, often for quantitative chemical analysis.
Stepper Motor – A type of motor that moves in discrete steps, often used for precise control of position.
Systematic Error – Consistent, repeatable error associated with faulty equipment or flawed technique.
UART – Universal Asynchronous Receiver/Transmitter, responsible for serial communication within an embedded system.
WCAG – Web Content Accessibility Guidelines.

## Appendix F – Electrical Schematics

Appendix F presents the complete electrical schematic for the Automated Micropipetting System. The diagram illustrates the connections and integration of all the key components within the system including: Elegoo Mega 2560 microcontroller, stepper motor drivers, LAC board, power regulation units and user interface components (touchscreen display and numerical keypad), limit switches and auxiliary devices such as the buzzer.
The schematic is organised to show the data transmission and power connections:
- Power supply management: dedicated 12 V (LAC board) and 5 V (Stepper motor drivers, microcontroller, screen) regulated rails to ensure stable operation of components.
- Motor control: Stepper interfaced with microcontroller for co-ordination of movement of gantry system
- Actuator Control: PWM controlled linear actuator managed via LAC board
- User interface: UART-connected touchscreen display for primary user feedback, I2C auxiliary display (no longer used) and a numerical keypad for user inputs.
- Safety Features: End stop switches present on each axis for homing and positional reset protocols, with direct inputs to microcontroller for real time adjustments

Figure F.1: Complete electrical schematic of Automated Micropipetting System, detailing microcontroller connections, power management, and user I/O connections

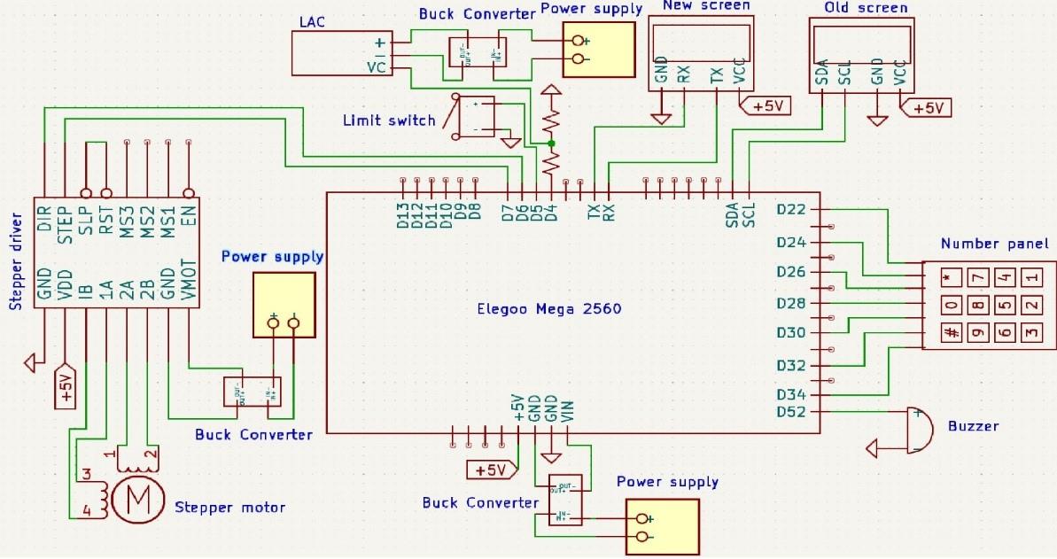
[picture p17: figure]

Note: visualised using KiCad.

complete electrical schematic for the Automated Micro pipetting System. The diagram illustrates the connections and integration of all the key components within the system including: Elegoo Mega 2560 microcontroller, stepper motor drivers, LAC board, power regulation units and user interface components (touchscreen display and numerical keypad), limit switches and auxiliary devices such as the buzzer.
The schematic is organised to show the data transmission and power connections:

- Power supply management: dedicated 12 V (LAC board) and 5 V (Stepper motor drivers, microcontroller, screen) regulated rails to ensure stable operation of components.
- Motor control: Stepper interfaced with microcontroller for co-ordination of movement of gantry system
- Actuator Control: PWM controlled linear actuator managed via LAC board
- User interface: UART-connected touchscreen display for primary user feedback, I2C auxiliary display (no longer used) and a numerical keypad for user inputs.
- Safety Features: End stop switches present on each axis for homing and positional reset protocols, with direct inputs to microcontroller for real time adjustments

Figure F.1: Complete electrical schematic of Automated Micropipetting System, detailing microcontroller connections, power management, and user I/O connections

Note: visualised using KiCad.

## Appendix G – Code

Figure G.1: Arduino Code Figure G.1: Arduino Code

## Appendix G – Code

Figure G.1: Arduino Code

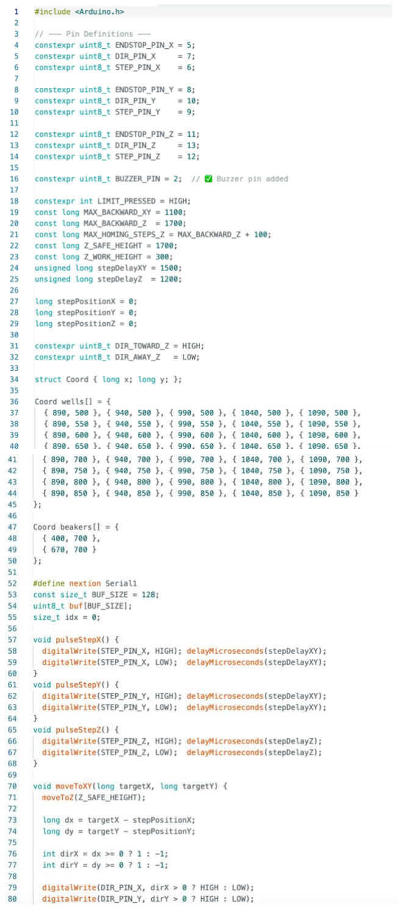
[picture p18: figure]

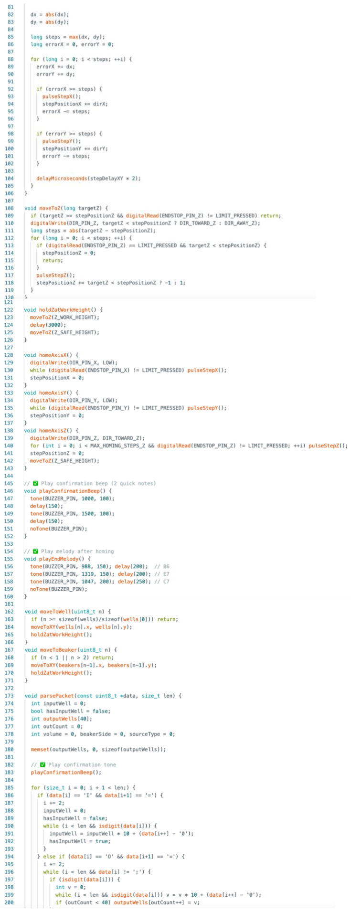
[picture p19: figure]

## Appendix H – User Instructions

### 1. Getting Started

1.1 Powering On
- Plug the system into a standard mains outlet (230V) to turn it on.
- Wait for the interface screen to initialize.
1.2 Preparing the Labware
- Ensure the source container (beaker or microcentrifuge tube) is filled with the desired liquid. This can be done by the user or a trained laboratory technician.
- Place your beaker or 1.5 mL microcentrifuge tubes in the clearly marked positions on the base of the device, similarly, done by the user or a trained technician.
2. Using the Touchscreen Interface
The interface guides the user step-by-step through the pipetting process. Below is an overview of each screen and its functionality. Use the Home button to return to the main screen at any time.

### 2.1 Page 0 – Source Type Selection

What you see:
- Image buttons/touch icons representing a beaker and tubes (Figure H1). Action:
- Tap on the image that corresponds to your liquid source.
Features:
- A Reset button (top-right) restores default settings. Choose either "Beaker" or "Tubes" to proceed.

Figure H.1: Initial Screen - touch icons on display for different sources (beaker or volume) to take up liquid.

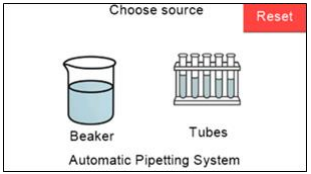
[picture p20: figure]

Note: GUI designed using Nextion.

### 2.2 Page 1a – Beaker Position Selection (only appears if “Beaker” is chosen)

What you see:
- Option to select either Left or Right beaker position (Figure H2).

Action:
- Tap the correct side depending on where your source beaker is placed. Navigation:
- Use the Back button to return to the source type screen if needed.

Figure H.2: Touch icons on display for selecting the left or right beaker.

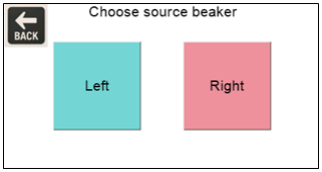
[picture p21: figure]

Note: GUI designed using Nextion. `

### 2.3 Page 1b – Input Well Selection (only appears if “Tubes” are chosen)

What you see:
- A 5×8 grid representing available wells, with coloured boxes for orientation. Action:
- Select one input well by tapping a box. Then press Confirm to lock in your choice.
Navigation:
- Use the Back button to return to the source type screen if needed.

Figure H.3: 5x8 Grid displaying source wells

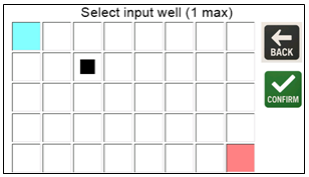
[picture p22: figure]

Note: GUI designed using Nextion.

### 2.4 Page 2 – Output Wells Selection

What you see:
- A second 5×8 grid for selecting one or more output wells. Action:
- Tap the desired wells, then press Confirm to store your choices. Navigation:
- Clear button resets your selections.
- Back button returns to the previous screen.

Figure H.3: 5x8 Grid displaying output wells

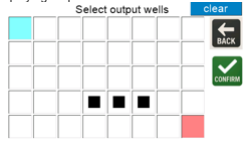
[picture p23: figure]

Note: GUI designed using Nextion.

Page 3 – Volume Entry and Final Confirmation

What you see:
- A numeric keypad to enter pipetting volume in microliters (Figure H5). Action:
- Enter a volume between 10 µL and 100 µL.
Navigation:
- Tap Delete to correct any entry errors.
- Tap Start Pipetting to begin the process.

Figure H.5: Numeric keypad displayed on touchscreen to choose desire volume to aspirate/dispense.

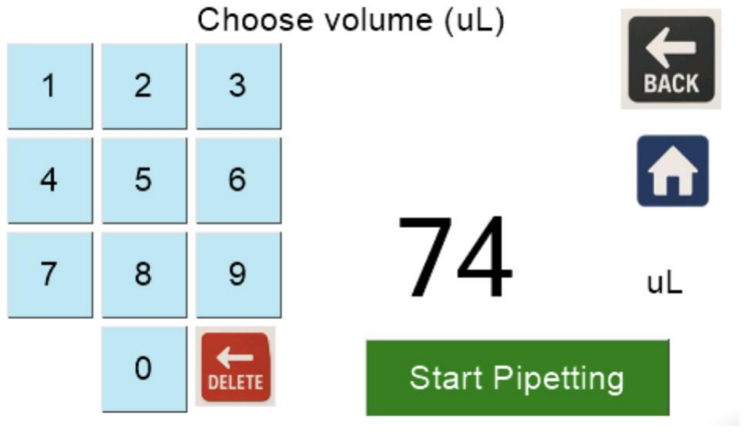
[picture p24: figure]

Note: GUI designed using Nextion. .

Rules/Errors:

- Only one input well can be selected, and if no well is selected, a warning will appear.
- At least one output well must be selected.
- If a well is selected as input, it cannot also be selected as output, and vice versa. The system will prevent and warn you if this occurs, even when navigating backwards.
- The system checks if the volume is within range, if not, a warning appears and disappears after a short delay.

## Appendix I – Gantry Calibration Data

To ensure accurate and reproducible positioning of the pipette head, the gantry system was calibrated along all three axes (X,Y and Z). The goal of this calibration was to establish a reliable conversion between stepper motor pulses and real-world displacement, enabling precise control of pipette’s movement during pipetting cycle.

Calibration was carried out by temporarily attaching a pencil to the gantry system in place of a pipette, allowing visible marking of the travel endpoints. Displacements were measured using a ruler at multiple pulse intervals to evaluate both linearity and precision of movement.

A linear regression method was then implemented to determine the step-to-distance ratio (mm/step) for each axis. The slope of the line of best-fit for each dataset represents the conversion co-efficient which is used to accurately control displacement. The calculated value are shown in Table G1, and the relevant plots in Figure G1.

Axis | Mm / step
X | 0.19
Y | 0.20
Z | 0.04

Table I.1: Calibrated stepper motor resolution for each axis.

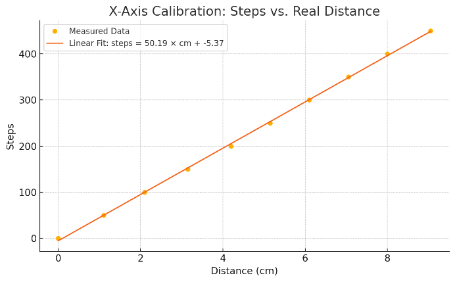
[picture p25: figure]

Figure G.1: Gantry calibration plots for X, Y axes

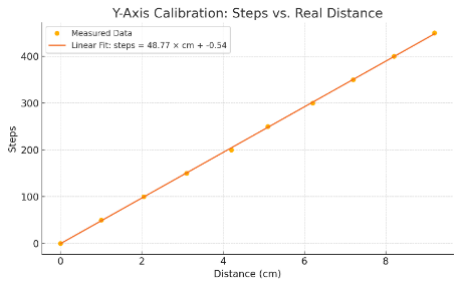
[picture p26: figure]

Note: Measured displacement versus step motor pulse counts for each gantry axis. A linear regression was applied to determine the displacement per step. The results show consistent movements in X, Y, Z. These results validate the system’s ability to achieve repeatable and accurate positioning across dimensions.

## Appendix J – User-Testing Results/Comments


Figure J.1: Response to survey about medical issues

Figure J.2: Portability Satisfaction

Figure J.3: Aesthetic Satisfaction


Figure J.4: Feasibiliy

Figure J.5: Clarity

Figure J.6: Ease of use

Figure J.7: Improvements


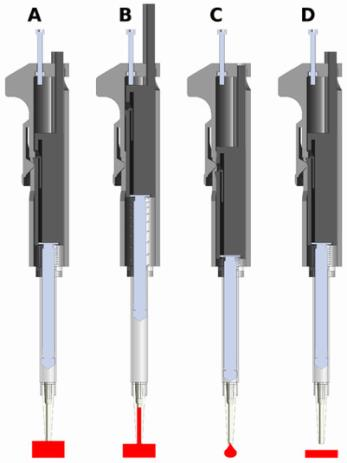
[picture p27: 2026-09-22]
docs/images/pipette-sequence.png

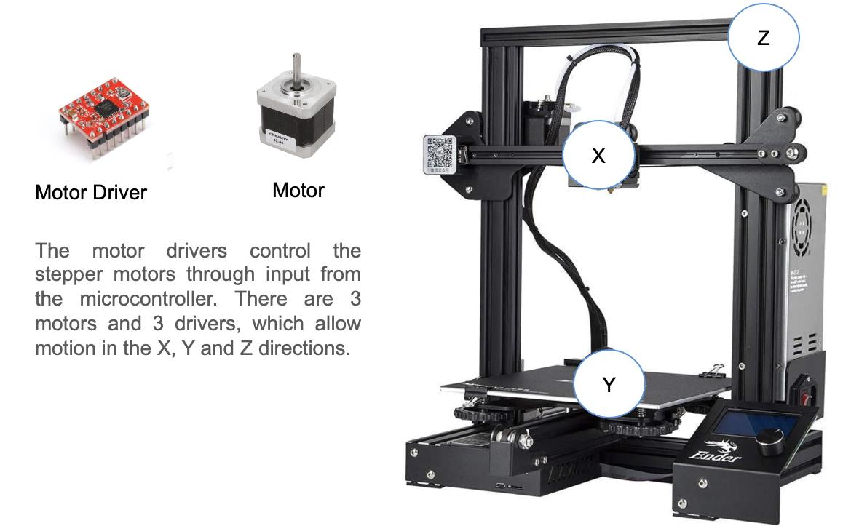
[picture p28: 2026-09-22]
docs/images/gantry.png

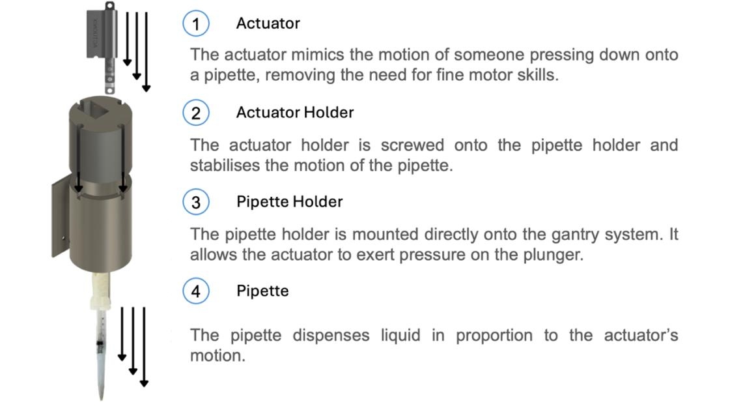
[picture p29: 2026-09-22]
docs/images/pipette-mechanism.png

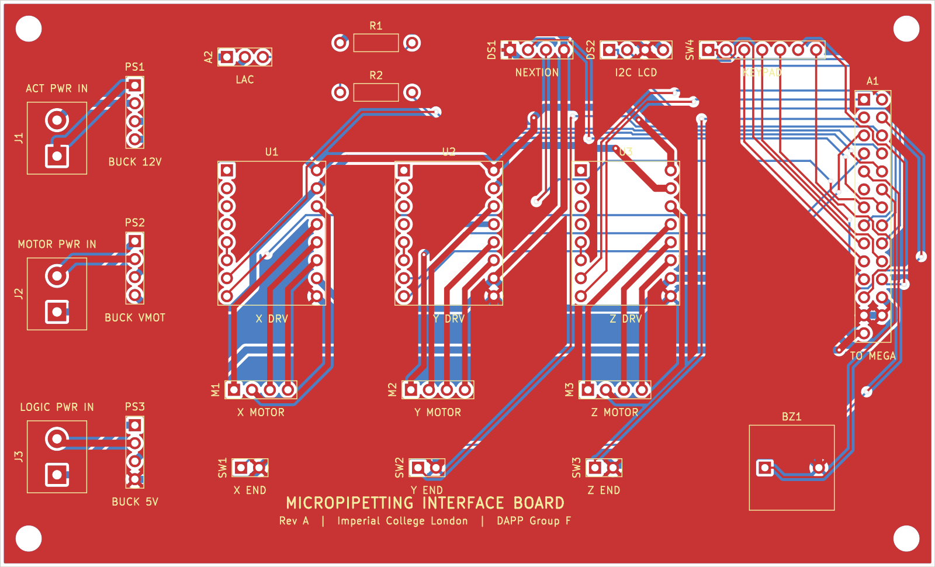
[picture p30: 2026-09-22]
docs/images/pcb-layout.png

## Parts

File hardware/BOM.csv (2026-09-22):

Subsystem | Component | MPN | Manufacturer | Supplier | Qty | Unit cost (GBP) | Total (GBP) | Notes
Electronics | Elegoo Mega 2560 R3 controller board | EL-CB-003 | Elegoo | Amazon | 1 | 21.98 | 21.98 | Arduino Mega compatible
Electronics | 2-layer bare rigid PCB | N/A | JLCPCB | JLCPCB | 1 | 99.22 | 99.22 | Custom interface PCB
Electronics | Header 8-pos 0.1in tin | PPTC081LFBN-RC | DigiKey | DigiKey | 19 | 0.496 | 9.42
Electronics | Terminal block 2-pos side entry 5.08mm | 277-1258-ND | DigiKey | DigiKey | 1 | 1.20 | 1.20
Electronics | LM2596 DC-DC adjustable buck converter | 552440 | Switch Electronics | Switch Electronics | 5 | 1.95 | 9.75 | 4.5-40 V in
Electronics | A4988 stepper driver module | D-A4988 | Oosznest | Oosznest | 4 | 4.52 | 18.08 | Up to 35 V / 1.5 A; full to 1/16 microstep
Gantry | Creality Ender-3 3D printer | Ender-3 | Creality | Creality Official Store | 1 | 139.00 | 139.00 | Frame / motion system / PSU / end-stops
Pipette | 3 mL syringe (10 pack) | 732489269615 | GSSFASHION | Amazon | 1 | 5.48 | 5.48
Pipette | M3 x 35 mm hex socket cap screws (25 pcs) | 602451234203 | Sourcingmap | Amazon | 1 | 6.59 | 6.59 | Class 10.9
Pipette | M3 hex nut A2 stainless (20 pcs) | B08HL9VVHX | Ascot City | Amazon | 1 | 6.49 | 6.49 | DIN 934
Pipette | Standard compression spring | LC022D10M | Lee Spring | Lee Spring | 2 | 4.24 | 8.48
Pipette | Kynar Luer female lock to 5/32in (4.0 mm) ID tube | E-F-160049 | Eoxshop | Eoxshop | 1 | 27.36 | 27.36 | USP Class VI / ISO 594
Screen | Nextion 4.3in HMI NX4827T043 resistive 480x272 | 296683638009 | Nextion | eBay (SONOFF Store) | 1 | 52.79 | 52.79
Screen | 32 GB microSD card | B0DRNNH8JR | Phison | Amazon | 1 | 11.98 | 11.98 | For loading Nextion .tft
Actuator | Actuonix linear actuator control (LAC) board | RB-Fir-121 | Actuonix | RobotShop | 1 | 10.01 | 10.01
Actuator | Kitronik linear actuator micro servo kit | 2595 | Kitronik | Kitronik | 1 | 18.95 | 18.95
Maintenance/testing | Hand exerciser grip strengthener (4 pack) | 741416340358 | Portholic | Amazon | 1 | 13.98 | 13.98 | Used to simulate reduced dexterity in user testing
Maintenance/testing | Motip freezer electronic spray 360 mL | M090409 | Motip | Amazon | 1 | 15.28 | 15.28 | Non-flammable
Maintenance/testing | Loctite universal super glue | 5010305061236 | Loctite | Amazon | 1 | 7.49 | 7.49

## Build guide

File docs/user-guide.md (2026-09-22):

# User guide

---

## Setup

1. Plug the system into mains power (230 V) and wait for the touchscreen to start up. The gantry homes automatically.
2. Fill the source beaker or tubes. You or a technician can do this.
3. Place the labware in the marked slots on the base. The grooves guide each item into position.
4. Fit a fresh pipette tip.

---

## Running a job

1. **Choose source:** tap Beaker or Tubes. Reset clears all your selections.
2. **Pick the source:**
   - Beaker: tap Left or Right.
   - Tubes: tap one well on the grid, then Confirm.
3. **Output wells:** tap one or more wells, then Confirm. Clear resets the grid.
4. **Volume:** enter the volume in µL and tap Start Pipetting.

A two-tone beep confirms the job. A short melody plays when the head has returned home.

Back takes you to the previous screen, and Home returns to the start. The system warns you and blocks the job if you select no input well, no output wells, the same well as both input and output, or an out-of-range volume.

---

## After use

- Remove the tips by hand. There is no auto-eject yet. Dispose of them according to your lab's waste protocol.
- Keep liquids away from the exposed electronics.

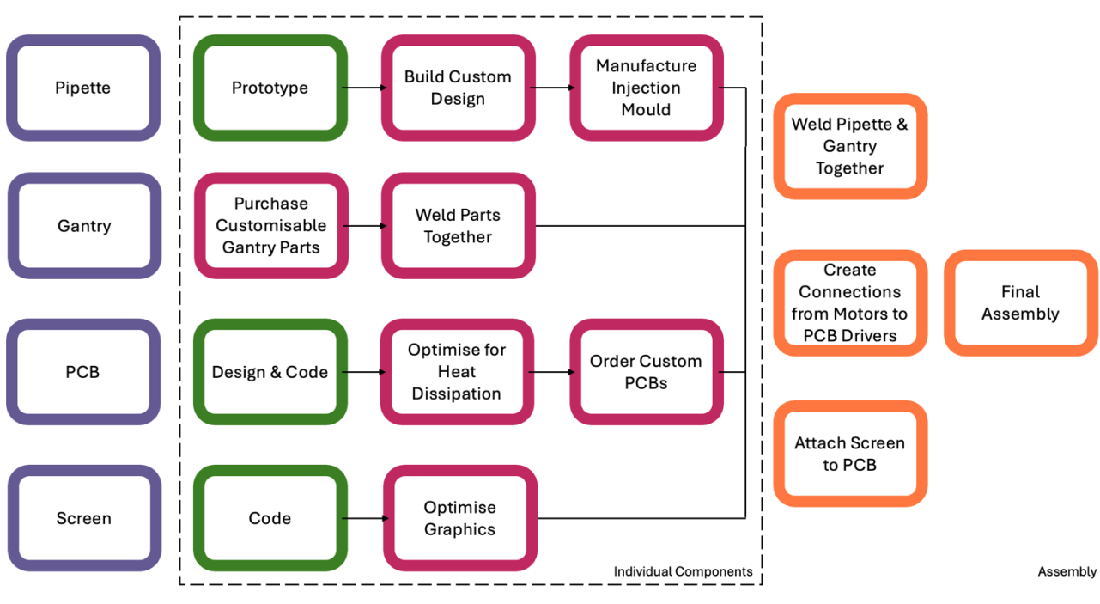
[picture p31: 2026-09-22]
docs/images/manufacturing-roadmap.png

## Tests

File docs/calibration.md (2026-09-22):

# Gantry calibration

---

## Method

1. A pencil was mounted in place of the pipette.
2. Each axis was driven in 50-step increments from 0 to 450 steps.
3. The resulting displacement was measured with a ruler.
4. A least-squares line was fitted to steps vs. distance.

---

## Results

| Axis | Fit | Steps/cm | mm/step |
|---|---|---|---|
| X | steps = 50.19·d − 5.37 | 50.19 | 0.199 |
| Y | steps = 48.77·d − 0.54 | 48.77 | 0.205 |
| Z | — | — | 0.04 |

The report table rounds these to 0.19 / 0.20 / 0.04 mm/step. No plot was produced for Z.

<p>

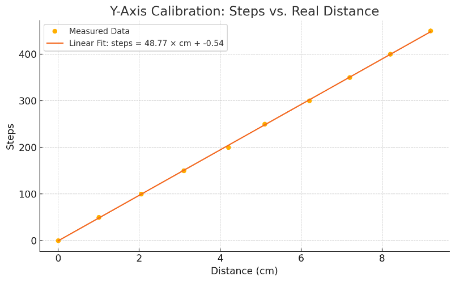
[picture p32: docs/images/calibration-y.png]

</p>

The response is linear across the full range, so a single scale factor per axis is enough. The firmware works in raw steps, so these factors are only needed to convert labware positions measured in mm into step coordinates.

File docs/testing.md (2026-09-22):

# Testing & evaluation

---

## Volumetric accuracy

1. Set a target volume.
2. Dispense it and weigh the output on a balance.
3. Compare the result against a manual micropipette.
4. Recalibrate the pipette to minimise the error.

**Result:** The pipette alone met ±1% after its graduations were recalibrated. The actuator adds extra uncertainty at system level. Accuracy and precision drop as the volume decreases.

---

## Cross-contamination

1. Run dyed liquid through the system.
2. Replace the tip.
3. Dispense clear liquid.

**Result:** There was no visible carryover. This check was qualitative only. A spectrophotometer absorbance check would be the quantitative follow-up.

---

## Gantry

The gantry was tested for:

- positional error against target on each axis,
- repeatability, by returning to the same point over repeated cycles, and
- speed, timed with `micros()`.

All tests were run at room temperature and pressure. See [calibration](calibration.md).

---

## Display

The display was checked for:

- the correct default screen on boot,
- the GUI loading from microSD,
- the response of every touch element,
- uniform pixel brightness, and
- stability over several hours of running.

---

## User testing

There were 20 participants. Seven reported conditions that limit their mobility. The rest wore finger resistance bands to simulate reduced dexterity, and the team's disability consultant endorsed this as a reasonable proxy.

| Question | Result |
|---|---|
| Fits into a lab (aesthetics) | 90% rated 4–5 |
| UI clarity | 55% "minimal instructions", 20% "no instructions", 25% "somewhat easy" |
| Ease of dispensing | 65% rated 4–5, 35% rated 3 |
| Would use regularly | 70% rated 4–5 |
| Portability | 45% rated 3 ("easy in less intense periods"), 45% rated 4–5, 10% rated 2 |
| Aspirate vs. dispense difficulty | 100% saw no difference |

Participants' free-text comments asked for a bigger screen, bigger touch icons, tactile buttons, and higher speed or throughput.

---

## Evaluation against the product specification

| Requirement | Outcome |
|---|---|
| 100 µL–1 mL within ±1% | Partial: the pipette passes, the actuator adds error |
| Chemical compatibility | Partial: PLA is moderately resistant, but long-term exposure was not tested |
| Splash-free dispensing | Pass |
| Contamination-free | Partial: visual check only |
| Simple operation | Pass |
| Bluetooth control | Dropped in favour of touchscreen and keypad after user feedback |
| Fits on a lab bench | Pass (44 × 44 × 46.5 cm) |
| < 10 kg | Pass |
| Visual/audio feedback | Pass |
| Reduces physical strain | Pass |
| Mains-compatible power | Pass (24 W) |
| Maintainable | Pass |
| < £600 | Pass (£483.53) |
| Broad accessibility | Partial |

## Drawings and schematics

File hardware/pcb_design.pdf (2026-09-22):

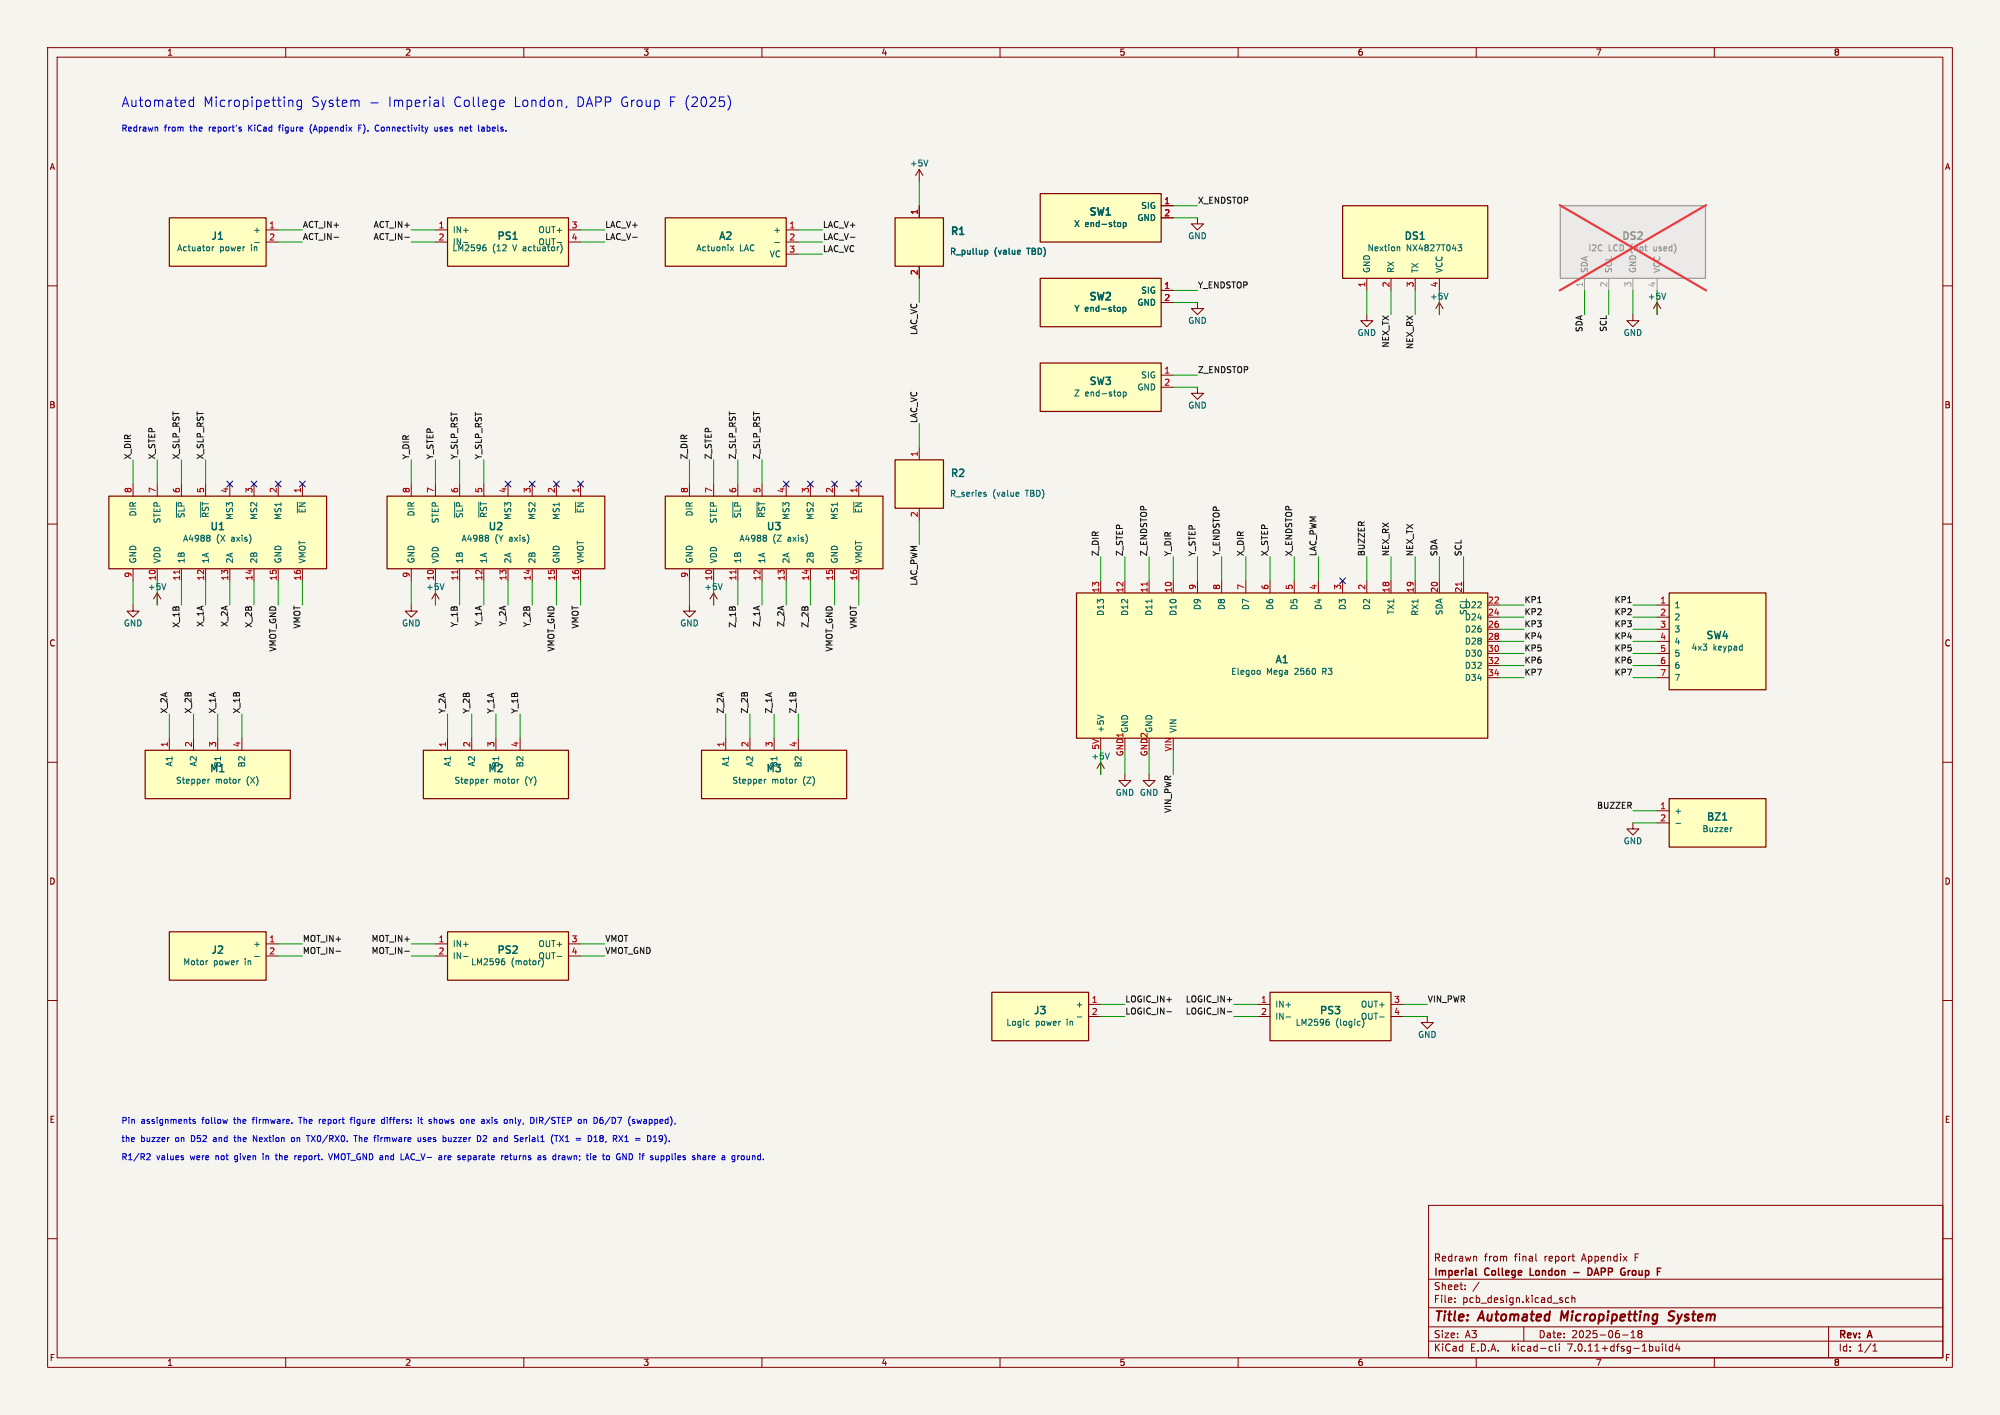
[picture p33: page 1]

1 2 R2 R_series (value TBD) SIG 1 GND SW3 2 Z end-stop SIG 1 GND SW1 2 X end-stop A1

4 DS1 Nextion NX4827T043 GND GND GND

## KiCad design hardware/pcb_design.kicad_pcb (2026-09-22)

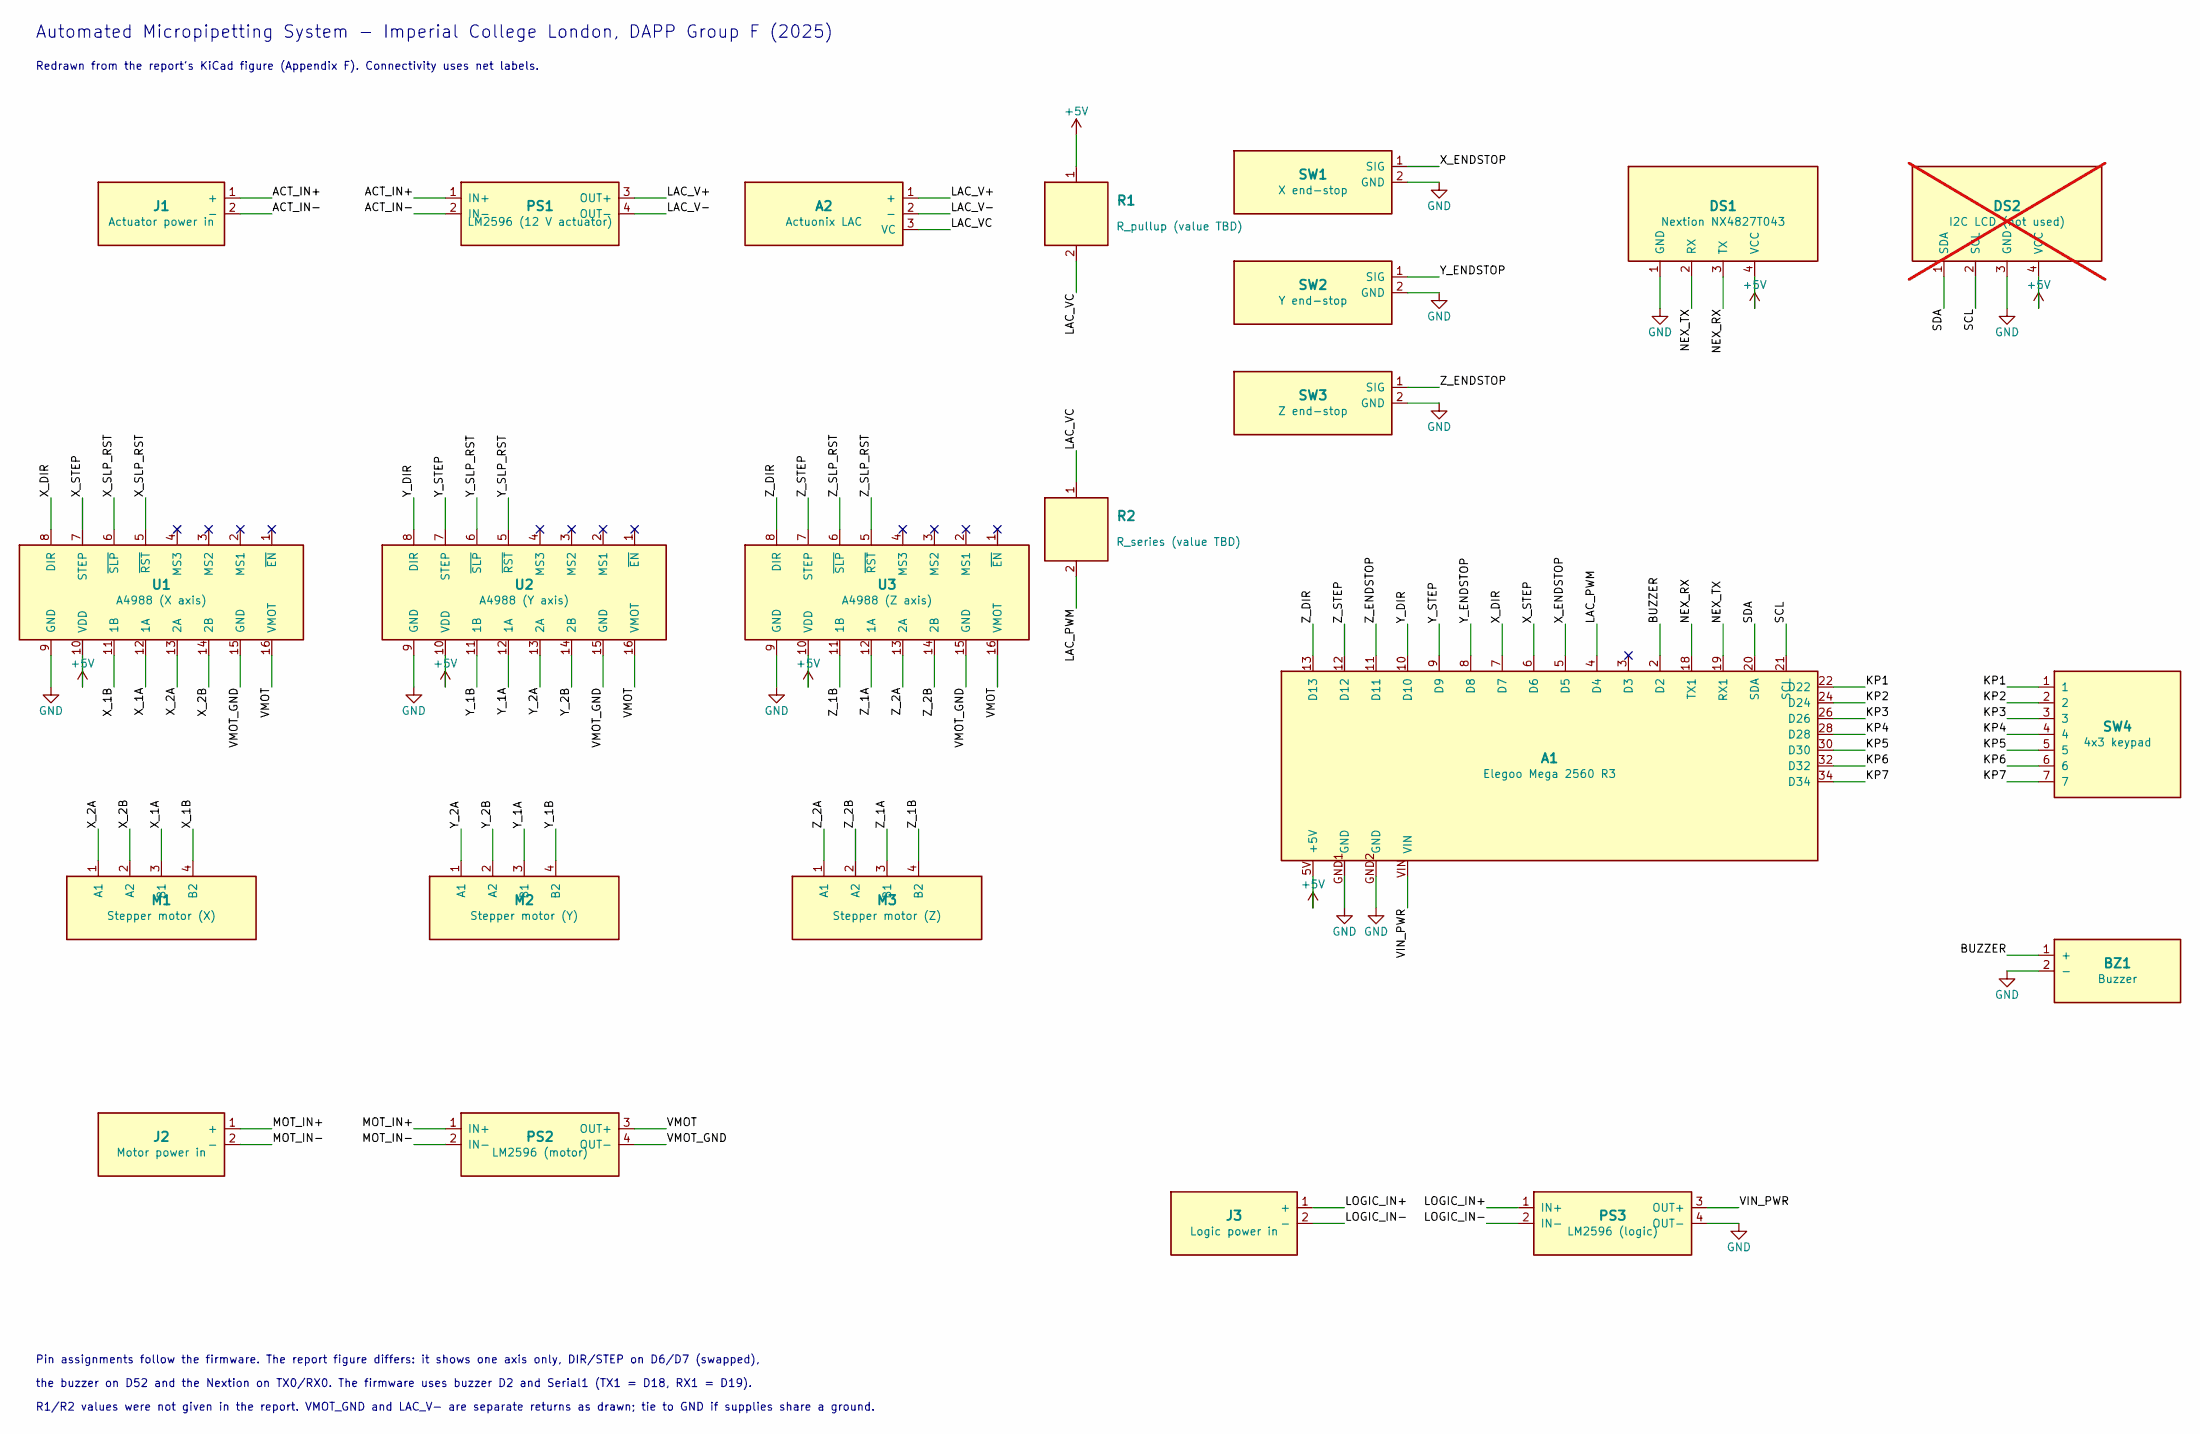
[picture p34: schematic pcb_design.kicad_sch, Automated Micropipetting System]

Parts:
A1: Elegoo Mega 2560 R3; Mega2560_Interface_2x14_P2.54mm
A2: Actuonix LAC; PinHeader_1x03_P2.54mm
BZ1: Buzzer; Buzzer_12x9.5RM7.6
DS1: Nextion NX4827T043; PinHeader_1x04_P2.54mm
DS2: I2C LCD (not used); PinHeader_1x04_P2.54mm; not fitted
J1: Actuator power in; TerminalBlock_1x02_P5.08mm
J2: Motor power in; TerminalBlock_1x02_P5.08mm
J3: Logic power in; TerminalBlock_1x02_P5.08mm
M1: Stepper motor (X); PinHeader_1x04_P2.54mm
M2: Stepper motor (Y); PinHeader_1x04_P2.54mm
M3: Stepper motor (Z); PinHeader_1x04_P2.54mm
PS1: LM2596 (12 V actuator); LM2596_Module_Header_1x04
PS2: LM2596 (motor); LM2596_Module_Header_1x04
PS3: LM2596 (logic); LM2596_Module_Header_1x04
R1: R_pullup (value TBD); R_Axial_DIN0207_L6.3mm_P10.16mm
R2: R_series (value TBD); R_Axial_DIN0207_L6.3mm_P10.16mm
SW1: X end-stop; PinHeader_1x02_P2.54mm
SW2: Y end-stop; PinHeader_1x02_P2.54mm
SW3: Z end-stop; PinHeader_1x02_P2.54mm
SW4: 4x3 keypad; PinHeader_1x07_P2.54mm
U1: A4988 (X axis); Pololu_A4988_Carrier_Socket
U2: A4988 (Y axis); Pololu_A4988_Carrier_Socket
U3: A4988 (Z axis); Pololu_A4988_Carrier_Socket

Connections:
+5V: A1.5V (+5V), DS1.4 (VCC), DS2.4 (VCC), R1.1, U1.10 (VDD), U2.10 (VDD), U3.10 (VDD)
/ACT_IN+: J1.1 (+), PS1.1 (IN+)
/ACT_IN-: J1.2 (-), PS1.2 (IN-)
/BUZZER: A1.2 (D2), BZ1.1 (+)
/KP1: A1.22 (D22), SW4.1
/KP2: A1.24 (D24), SW4.2
/KP3: A1.26 (D26), SW4.3
/KP4: A1.28 (D28), SW4.4
/KP5: A1.30 (D30), SW4.5
/KP6: A1.32 (D32), SW4.6
/KP7: A1.34 (D34), SW4.7
/LAC_PWM: A1.4 (D4), R2.2
/LAC_V+: A2.1 (+), PS1.3 (OUT+)
/LAC_V-: A2.2 (-), PS1.4 (OUT-)
/LAC_VC: A2.3 (VC), R1.2, R2.1
/LOGIC_IN+: J3.1 (+), PS3.1 (IN+)
/LOGIC_IN-: J3.2 (-), PS3.2 (IN-)
/MOT_IN+: J2.1 (+), PS2.1 (IN+)
/MOT_IN-: J2.2 (-), PS2.2 (IN-)
/NEX_RX: A1.18 (TX1), DS1.3 (TX)
/NEX_TX: A1.19 (RX1), DS1.2 (RX)
/SCL: A1.21 (SCL), DS2.2 (SCL)
/SDA: A1.20 (SDA), DS2.1 (SDA)
/VIN_PWR: A1.VIN, PS3.3 (OUT+)
/VMOT: PS2.3 (OUT+), U1.16 (VMOT), U2.16 (VMOT), U3.16 (VMOT)
/VMOT_GND: PS2.4 (OUT-), U1.15 (GND), U2.15 (GND), U3.15 (GND)
/X_1A: M1.3 (B1), U1.12 (1A)
/X_1B: M1.4 (B2), U1.11 (1B)
/X_2A: M1.1 (A1), U1.13 (2A)
/X_2B: M1.2 (A2), U1.14 (2B)
/X_DIR: A1.7 (D7), U1.8 (DIR)
/X_ENDSTOP: A1.5 (D5), SW1.1 (SIG)
/X_SLP_RST: U1.5 (~RST), U1.6 (~SLP)
/X_STEP: A1.6 (D6), U1.7 (STEP)
/Y_1A: M2.3 (B1), U2.12 (1A)
/Y_1B: M2.4 (B2), U2.11 (1B)
/Y_2A: M2.1 (A1), U2.13 (2A)
/Y_2B: M2.2 (A2), U2.14 (2B)
/Y_DIR: A1.10 (D10), U2.8 (DIR)
/Y_ENDSTOP: A1.8 (D8), SW2.1 (SIG)
/Y_SLP_RST: U2.5 (~RST), U2.6 (~SLP)
/Y_STEP: A1.9 (D9), U2.7 (STEP)
/Z_1A: M3.3 (B1), U3.12 (1A)
/Z_1B: M3.4 (B2), U3.11 (1B)
/Z_2A: M3.1 (A1), U3.13 (2A)
/Z_2B: M3.2 (A2), U3.14 (2B)
/Z_DIR: A1.13 (D13), U3.8 (DIR)
/Z_ENDSTOP: A1.11 (D11), SW3.1 (SIG)
/Z_SLP_RST: U3.5 (~RST), U3.6 (~SLP)
/Z_STEP: A1.12 (D12), U3.7 (STEP)
GND: A1.GND1 (GND), A1.GND2 (GND), BZ1.2 (-), DS1.1 (GND), DS2.3 (GND), PS3.4 (OUT-), SW1.2 (GND), SW2.2 (GND), SW3.2 (GND), U1.9 (GND), U2.9 (GND), U3.9 (GND)

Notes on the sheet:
Automated Micropipetting System - Imperial College London, DAPP Group F (2025)
Redrawn from the report's KiCad figure (Appendix F). Connectivity uses net labels.
Pin assignments follow the firmware. The report figure differs: it shows one axis only, DIR/STEP on D6/D7 (swapped),
the buzzer on D52 and the Nextion on TX0/RX0. The firmware uses buzzer D2 and Serial1 (TX1 = D18, RX1 = D19).
R1/R2 values were not given in the report. VMOT_GND and LAC_V- are separate returns as drawn; tie to GND if supplies share a ground.

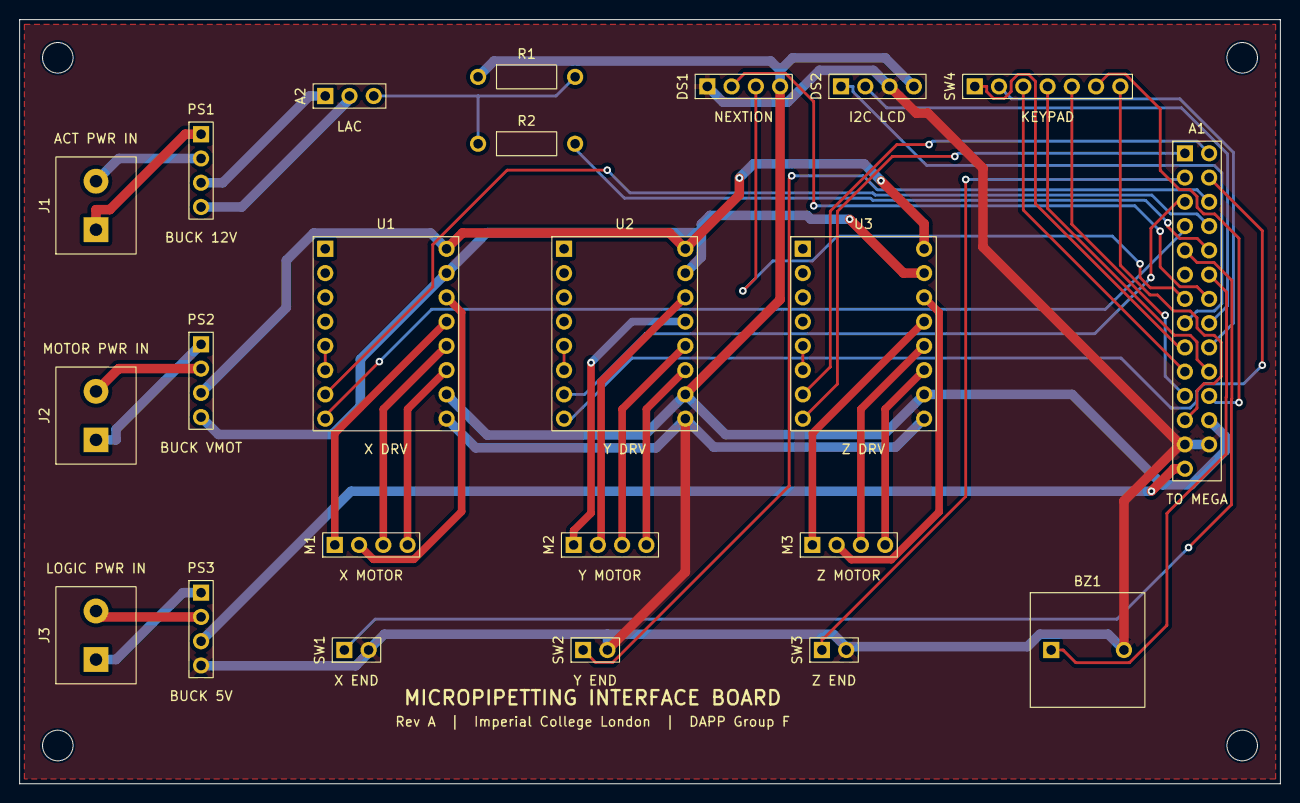
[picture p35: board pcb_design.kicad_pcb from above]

Board: 2 copper layers, 132.0 x 80.0 mm, 27 parts (0 on the bottom side), 51 nets.

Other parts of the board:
H1, H2, H3, H4: MountingHole_3.2mm_M3

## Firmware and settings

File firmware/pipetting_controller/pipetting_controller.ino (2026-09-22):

/*
 * Automated Micropipetting System - Gantry & UI Controller
 * Target: Elegoo Mega 2560 (ATmega2560)
 *
 * Drives a modified Creality Ender-3 gantry (3x A4988 stepper drivers),
 * homes against mechanical end-stops, and executes pipetting runs
 * received as packets from a Nextion NX4827T043 touchscreen on Serial1.
 *
 * Transcribed from Appendix G of the Group F final report (June 2025).
 * Logic is unchanged from the version demonstrated; see firmware/README.md
 * for the packet protocol and known limitations.
 */

#include <Arduino.h>

// --- Pin Definitions ---
constexpr uint8_t ENDSTOP_PIN_X = 5;
constexpr uint8_t DIR_PIN_X     = 7;
constexpr uint8_t STEP_PIN_X    = 6;

constexpr uint8_t ENDSTOP_PIN_Y = 8;
constexpr uint8_t DIR_PIN_Y     = 10;
constexpr uint8_t STEP_PIN_Y    = 9;

constexpr uint8_t ENDSTOP_PIN_Z = 11;
constexpr uint8_t DIR_PIN_Z     = 13;
constexpr uint8_t STEP_PIN_Z    = 12;

constexpr uint8_t BUZZER_PIN = 2;

// --- Motion configuration (units: steps) ---
constexpr int LIMIT_PRESSED = HIGH;
const long MAX_BACKWARD_XY = 1100;
const long MAX_BACKWARD_Z  = 1700;
const long MAX_HOMING_STEPS_Z = MAX_BACKWARD_Z + 100;
const long Z_SAFE_HEIGHT = 1700;   // travel height between positions
const long Z_WORK_HEIGHT = 300;    // tip-in-liquid height
unsigned long stepDelayXY = 1500;  // us, half-period of XY step pulse
unsigned long stepDelayZ  = 1200;  // us, half-period of Z step pulse

long stepPositionX = 0;
long stepPositionY = 0;
long stepPositionZ = 0;

constexpr uint8_t DIR_TOWARD_Z = HIGH;
constexpr uint8_t DIR_AWAY_Z   = LOW;

// --- Labware map (step coordinates relative to home) ---
struct Coord { long x; long y; };

// 5 x 8 tube rack, row-major (index 0..39), 50-step pitch (~10 mm)
Coord wells[] = {
  { 890, 500 }, { 940, 500 }, { 990, 500 }, { 1040, 500 }, { 1090, 500 },
  { 890, 550 }, { 940, 550 }, { 990, 550 }, { 1040, 550 }, { 1090, 550 },
  { 890, 600 }, { 940, 600 }, { 990, 600 }, { 1040, 600 }, { 1090, 600 },
  { 890, 650 }, { 940, 650 }, { 990, 650 }, { 1040, 650 }, { 1090, 650 },
  { 890, 700 }, { 940, 700 }, { 990, 700 }, { 1040, 700 }, { 1090, 700 },
  { 890, 750 }, { 940, 750 }, { 990, 750 }, { 1040, 750 }, { 1090, 750 },
  { 890, 800 }, { 940, 800 }, { 990, 800 }, { 1040, 800 }, { 1090, 800 },
  { 890, 850 }, { 940, 850 }, { 990, 850 }, { 1040, 850 }, { 1090, 850 }
};

// Source beakers: 1 = left, 2 = right
Coord beakers[] = {
  { 400, 700 },
  { 670, 700 }
};

// --- Nextion serial link ---
#define nextion Serial1
const size_t BUF_SIZE = 128;
uint8_t buf[BUF_SIZE];
size_t idx = 0;

// --- Low-level stepping ---
void pulseStepX() {
  digitalWrite(STEP_PIN_X, HIGH); delayMicroseconds(stepDelayXY);
  digitalWrite(STEP_PIN_X, LOW);  delayMicroseconds(stepDelayXY);
}
void pulseStepY() {
  digitalWrite(STEP_PIN_Y, HIGH); delayMicroseconds(stepDelayXY);
  digitalWrite(STEP_PIN_Y, LOW);  delayMicroseconds(stepDelayXY);
}
void pulseStepZ() {
  digitalWrite(STEP_PIN_Z, HIGH); delayMicroseconds(stepDelayZ);
  digitalWrite(STEP_PIN_Z, LOW);  delayMicroseconds(stepDelayZ);
}

// --- Coordinated XY move (Bresenham-style interpolation) ---
void moveToXY(long targetX, long targetY) {
  moveToZ(Z_SAFE_HEIGHT);

  long dx = targetX - stepPositionX;
  long dy = targetY - stepPositionY;

  int dirX = dx >= 0 ? 1 : -1;
  int dirY = dy >= 0 ? 1 : -1;

  digitalWrite(DIR_PIN_X, dirX > 0 ? HIGH : LOW);
  digitalWrite(DIR_PIN_Y, dirY > 0 ? HIGH : LOW);

  dx = abs(dx);
  dy = abs(dy);

  long steps = max(dx, dy);
  long errorX = 0, errorY = 0;

  for (long i = 0; i < steps; ++i) {
    errorX += dx;
    errorY += dy;

    if (errorX >= steps) {
      pulseStepX();
      stepPositionX += dirX;
      errorX -= steps;
    }

    if (errorY >= steps) {
      pulseStepY();
      stepPositionY += dirY;
      errorY -= steps;
    }

    delayMicroseconds(stepDelayXY * 2);
  }
}

// --- Z move with end-stop guard ---
void moveToZ(long targetZ) {
  if (targetZ == stepPositionZ && digitalRead(ENDSTOP_PIN_Z) != LIMIT_PRESSED) return;
  digitalWrite(DIR_PIN_Z, targetZ < stepPositionZ ? DIR_TOWARD_Z : DIR_AWAY_Z);
  long steps = abs(targetZ - stepPositionZ);
  for (long i = 0; i < steps; ++i) {
    if (digitalRead(ENDSTOP_PIN_Z) == LIMIT_PRESSED && targetZ < stepPositionZ) {
      stepPositionZ = 0;
      return;
    }
    pulseStepZ();
    stepPositionZ += targetZ < stepPositionZ ? -1 : 1;
  }
}

// Dip to working height, dwell, retract
void holdZatWorkHeight() {
  moveToZ(Z_WORK_HEIGHT);
  delay(3000);
  moveToZ(Z_SAFE_HEIGHT);
}

// --- Homing ---
void homeAxisX() {
  digitalWrite(DIR_PIN_X, LOW);
  while (digitalRead(ENDSTOP_PIN_X) != LIMIT_PRESSED) pulseStepX();
  stepPositionX = 0;
}
void homeAxisY() {
  digitalWrite(DIR_PIN_Y, LOW);
  while (digitalRead(ENDSTOP_PIN_Y) != LIMIT_PRESSED) pulseStepY();
  stepPositionY = 0;
}
void homeAxisZ() {
  digitalWrite(DIR_PIN_Z, DIR_TOWARD_Z);
  for (int i = 0; i < MAX_HOMING_STEPS_Z && digitalRead(ENDSTOP_PIN_Z) != LIMIT_PRESSED; ++i) pulseStepZ();
  stepPositionZ = 0;
  moveToZ(Z_SAFE_HEIGHT);
}

// --- Audio feedback ---
// Confirmation beep (2 quick notes) when a job is received
void playConfirmationBeep() {
  tone(BUZZER_PIN, 1000, 100);
  delay(150);
  tone(BUZZER_PIN, 1500, 100);
  delay(150);
  noTone(BUZZER_PIN);
}

// Melody when a job completes and the head returns home
void playEndMelody() {
  tone(BUZZER_PIN, 988, 150);  delay(200);  // B5
  tone(BUZZER_PIN, 1319, 150); delay(200);  // E6
  tone(BUZZER_PIN, 1047, 200); delay(250);  // C6
  noTone(BUZZER_PIN);
}

// --- Labware moves ---
void moveToWell(uint8_t n) {
  if (n >= sizeof(wells)/sizeof(wells[0])) return;
  moveToXY(wells[n].x, wells[n].y);
  holdZatWorkHeight();
}
void moveToBeaker(uint8_t n) {
  if (n < 1 || n > 2) return;
  moveToXY(beakers[n-1].x, beakers[n-1].y);
  holdZatWorkHeight();
}

// --- Nextion packet parser & job executor ---
// Packet fields (terminated by '#'):
//   I=<ascii digits>          input well index
//   O=<d>,<d>,...;            output well indices
//   V=<4 bytes LE>            volume (uL)
//   B=<4 bytes LE>            beaker side (1 = left, 2 = right)
//   T=<4 bytes LE>            source type (1 = beaker, 2 = tubes)
void parsePacket(const uint8_t *data, size_t len) {
  int inputWell = 0;
  bool hasInputWell = false;
  int outputWells[40];
  int outCount = 0;
  int volume = 0, beakerSide = 0, sourceType = 0;

  memset(outputWells, 0, sizeof(outputWells));

  playConfirmationBeep();

  for (size_t i = 0; i + 1 < len;) {
    if (data[i] == 'I' && data[i+1] == '=') {
      i += 2;
      inputWell = 0;
      hasInputWell = false;
      while (i < len && isdigit(data[i])) {
        inputWell = inputWell * 10 + (data[i++] - '0');
        hasInputWell = true;
      }
    } else if (data[i] == 'O' && data[i+1] == '=') {
      i += 2;
      while (i < len && data[i] != ';') {
        if (isdigit(data[i])) {
          int v = 0;
          while (i < len && isdigit(data[i])) v = v * 10 + (data[i++] - '0');
          if (outCount < 40) outputWells[outCount++] = v;
        } else i++;
      }
    } else if (data[i] == 'V' && data[i+1] == '=') {
      if (i+6 <= len) volume = data[i+2] | (data[i+3]<<8) | (data[i+4]<<16) | (data[i+5]<<24);
      i += 6;
    } else if (data[i] == 'B' && data[i+1] == '=') {
      if (i+6 <= len) beakerSide = data[i+2] | (data[i+3]<<8) | (data[i+4]<<16) | (data[i+5]<<24);
      i += 6;
    } else if (data[i] == 'T' && data[i+1] == '=') {
      if (i+6 <= len) sourceType = data[i+2] | (data[i+3]<<8) | (data[i+4]<<16) | (data[i+5]<<24);
      i += 6;
    } else i++;
  }

  Serial.print("Input Well: "); Serial.println(inputWell);
  Serial.print("Output Wells: "); for (int j = 0; j < outCount; ++j) { Serial.print(outputWells[j]); Serial.print(","); } Serial.println();
  Serial.print("Volume: "); Serial.println(volume);
  Serial.print("Beaker Side: "); Serial.println(beakerSide);
  Serial.print("Source Type: "); Serial.println(sourceType);

  if (sourceType == 1 && beakerSide >= 1 && beakerSide <= 2) {
    moveToBeaker(beakerSide);
    for (int i = 0; i < outCount; ++i) moveToWell(outputWells[i]);
  } else if (sourceType == 2 && hasInputWell) {
    moveToWell(inputWell);
    for (int i = 0; i < outCount; ++i) moveToWell(outputWells[i]);
  }

  moveToZ(Z_SAFE_HEIGHT);
  moveToXY(0, 0);

  stepPositionX = 0;
  stepPositionY = 0;

  playEndMelody();

  memset(buf, 0, sizeof(buf));
  idx = 0;
}

void setup() {
  Serial.begin(9600);
  nextion.begin(9600);
  delay(300);
  while (nextion.available()) nextion.read();

  pinMode(BUZZER_PIN, OUTPUT);

  pinMode(ENDSTOP_PIN_X, INPUT_PULLUP); pinMode(DIR_PIN_X, OUTPUT); pinMode(STEP_PIN_X, OUTPUT);
  pinMode(ENDSTOP_PIN_Y, INPUT_PULLUP); pinMode(DIR_PIN_Y, OUTPUT); pinMode(STEP_PIN_Y, OUTPUT);
  pinMode(ENDSTOP_PIN_Z, INPUT_PULLUP); pinMode(DIR_PIN_Z, OUTPUT); pinMode(STEP_PIN_Z, OUTPUT);

  homeAxisX(); homeAxisY(); homeAxisZ();
  Serial.println("Ready to receive Nextion packets...");
}

void loop() {
  while (nextion.available()) {
    uint8_t b = nextion.read();
    if (b == '#') {
      if (idx > 0) {
        parsePacket(buf, idx);
      }
    } else if (idx < BUF_SIZE) {
      buf[idx++] = b;
    }
  }

  // Debug: manual re-homing over USB serial
  if (Serial.available()) {
    String in = Serial.readStringUntil('\n');
    in.trim();
    if (in.equalsIgnoreCase("X0")) homeAxisX();
    else if (in.equalsIgnoreCase("Y0")) homeAxisY();
    else if (in.equalsIgnoreCase("Z0")) homeAxisZ();
  }
}

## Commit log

2026-09-22 Initial commit: firmware, KiCad schematic and PCB, docs
    [BOM.csv, pcb_design.kicad_pcb, pcb_design.kicad_sch]
2026-09-24 Change PCB layout image to PCB render
    Updated PCB image reference in README.
2026-09-24 Replace layout image with PCB render
2026-09-24 Point READMEs at PCB render
